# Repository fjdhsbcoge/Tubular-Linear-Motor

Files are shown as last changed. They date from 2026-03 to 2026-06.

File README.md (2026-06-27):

# Tubular Linear Motor

Open-source tubular linear motor with FOC control. **Parametric design** — scalable dimensions with invariant ratios.

## Design Overview

This project provides a **general parametric design** for tubular linear motors that can be scaled to different sizes while maintaining proper field geometry. The repository also documents a **specific test setup** being built for initial verification.

## CAD Design

Cross-sectional view showing the internal structure with stator magnets and coil arrangement:

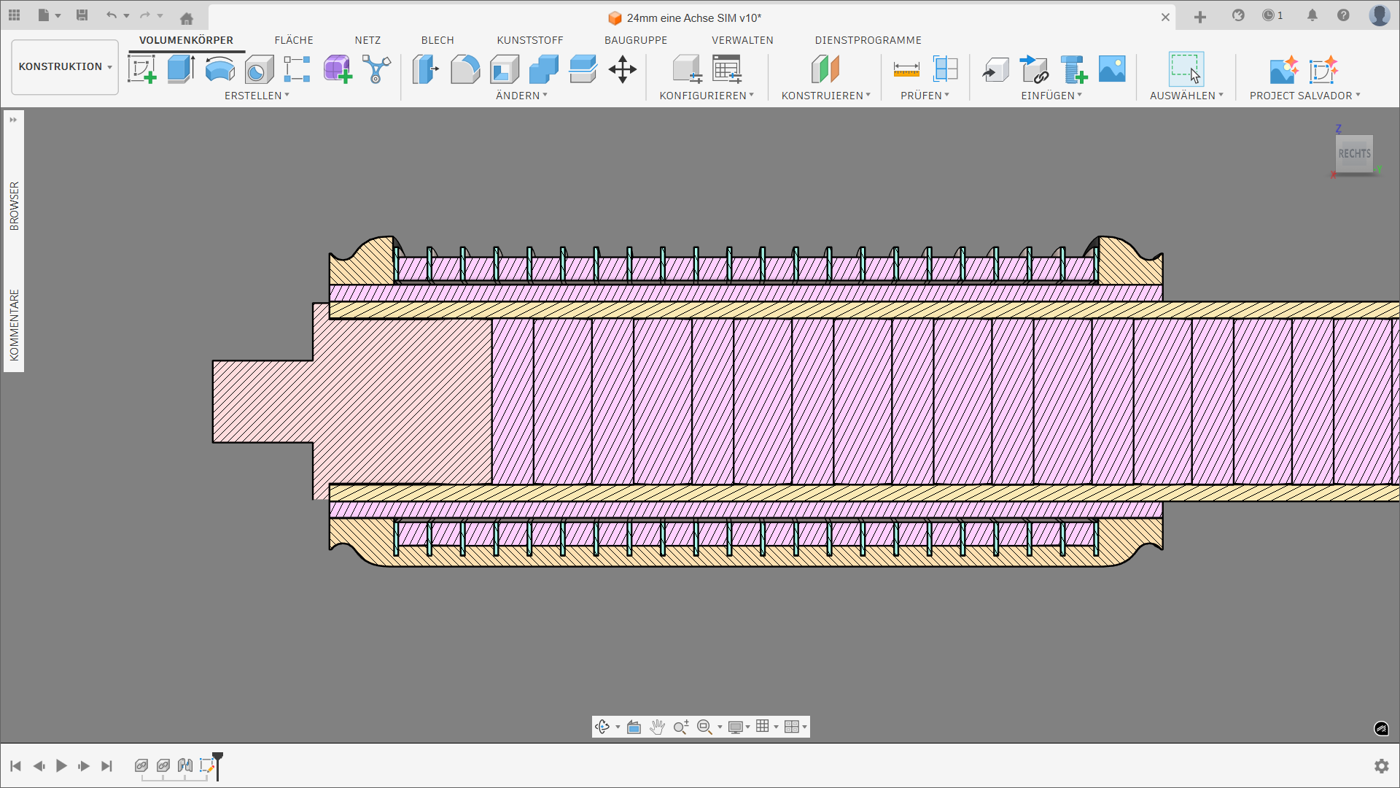
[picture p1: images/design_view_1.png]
Design View 1 - Cross Section


3D render showing the complete mover assembly with copper windings and carbon fiber housing:

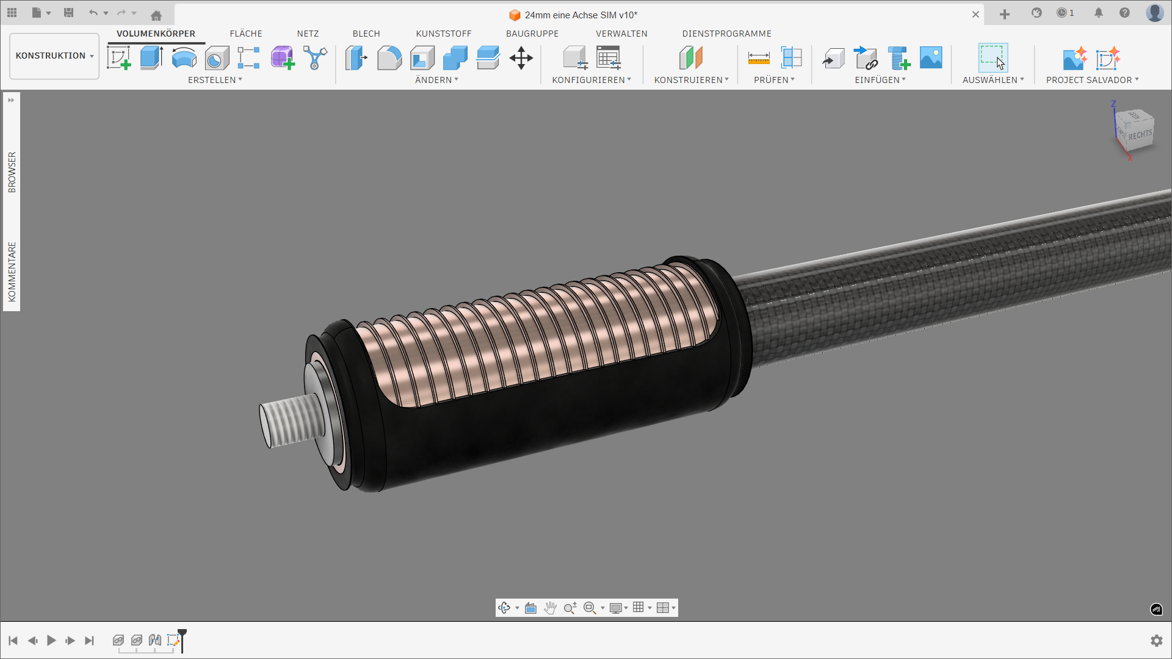
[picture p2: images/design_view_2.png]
Design View 2 - 3D Render


## Magnetic Field Simulations

The motor operates on a magnetic gearing principle where two sine-wave fields interlock like gear teeth. FEMM simulations visualize this interaction: field lines show the flux paths from the stator magnets, while the B-field plots demonstrate the sinusoidal pattern that creates the "magnetic gear rack" the mover engages with.

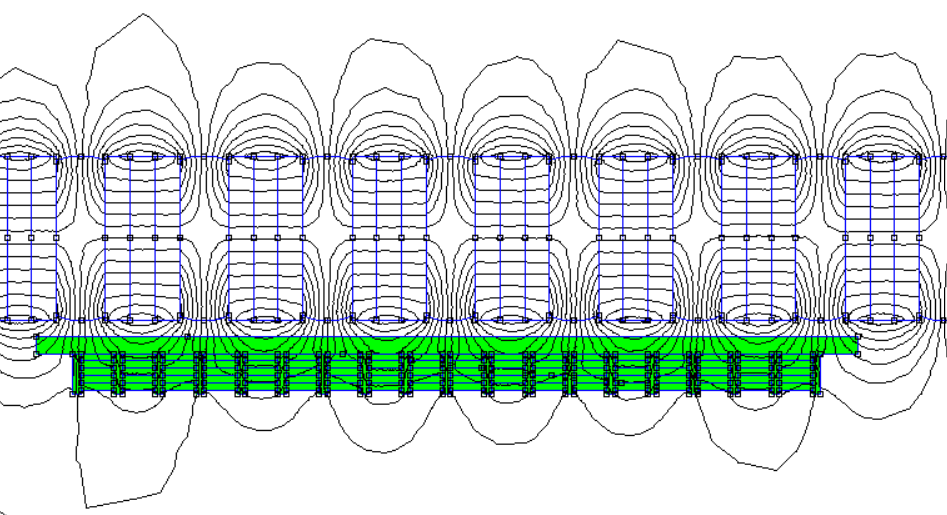
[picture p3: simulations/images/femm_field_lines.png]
Field Lines

*Magnetic field lines from the stator permanent magnets*

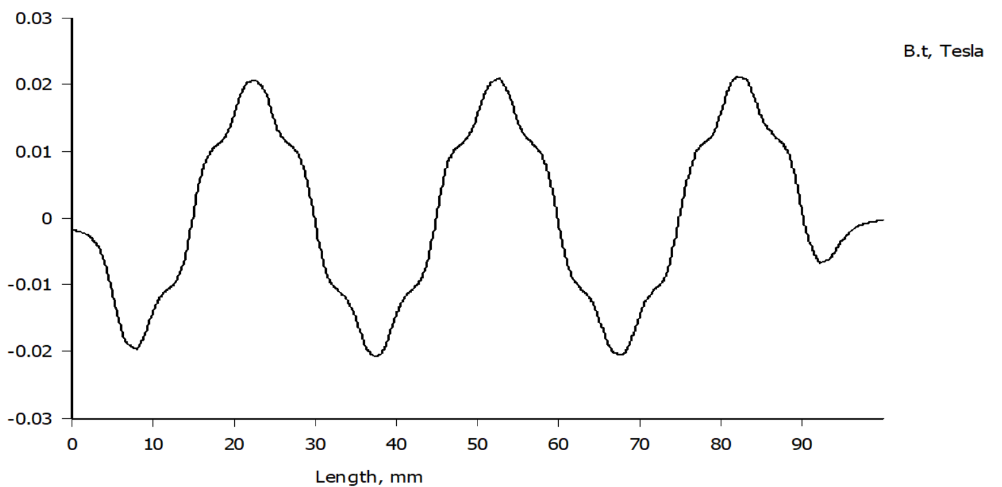
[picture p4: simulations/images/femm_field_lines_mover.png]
B-Field Plot

*Flux density along the mover length*

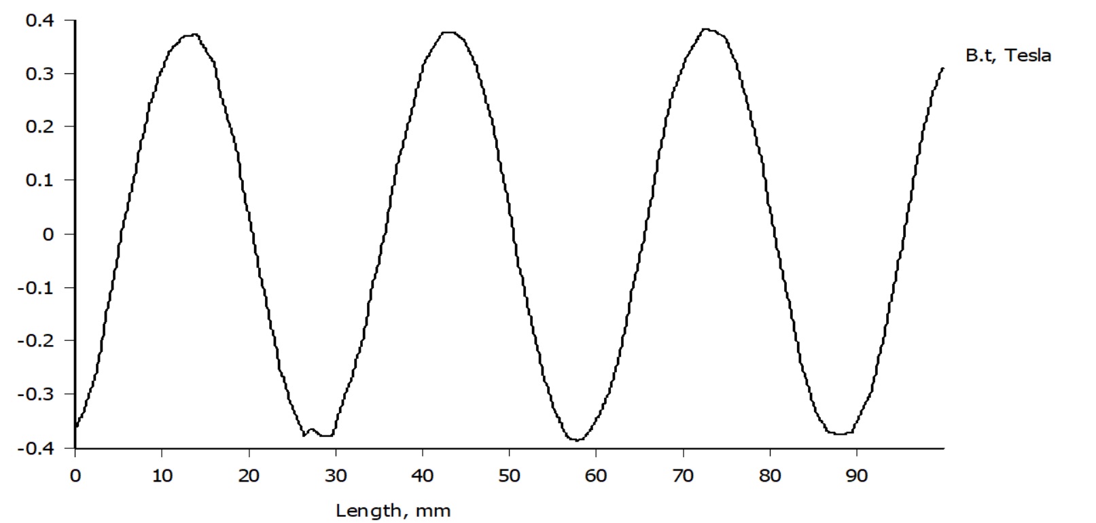
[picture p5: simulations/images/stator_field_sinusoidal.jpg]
Stator Field

*Sinusoidal B-field along the stator — each period corresponds to one pole pair (N-S), forming the "teeth" of the magnetic gear*

### Parametric Design Principles

The motor follows these invariant relationships:

| Ratio | Value | Description |
|---|---|---|
| Coil width / Pole pitch | 1/6 | 6 coils per pole pitch (AbCaBc) |
| Spacer width / Magnet width | 0.9–1.2 | Flux shaping optimization |
| Edge rounding | ~5 × disk diameter | Sinusoidal field formation |

**General Formula:**
```
Mover: AbCaBc repeated X times
Width of one AbCaBc block = Pole pitch (λ)
Total mover length = X × λ
```
### Test Setup (Being Verified)

The simulations and CAD files in this repository represent a specific test configuration:

| Parameter | Value |
|---|---|
| Outer Diameter | 20 mm |
| Pole Pitch (λ) | 30 mm |
| Coil Width | 5 mm (λ/6) |
| Mover Length | 90 mm (3× λ) |
| Simulated Force | 60 N at 2 A |

See [docs/DESIGN_PRINCIPLES.md](docs/DESIGN_PRINCIPLES.md) for complete scaling guidelines and how to choose electrical parameters (resistance, inductance) based on driver capabilities and force requirements.

## Update July 2026:

Back EMF was measured, moving the coils by hand over the stator arrangement fast gives this voltage response:

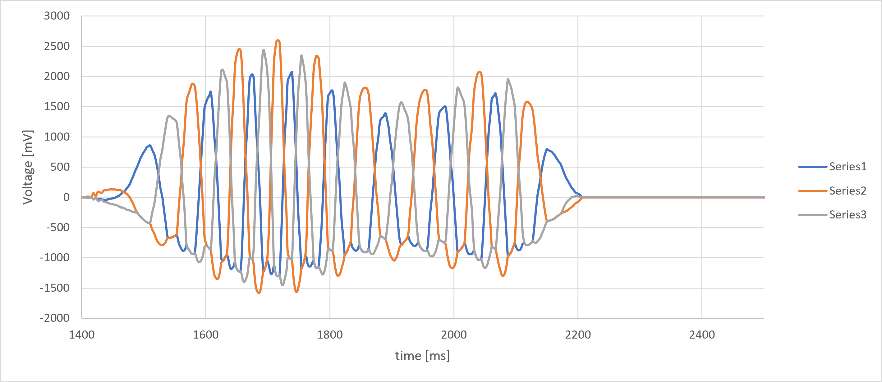
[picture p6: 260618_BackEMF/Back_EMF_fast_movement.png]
BACK EMF moving the protoype mover by hand fast


The voltage lines show a threephase response, exactly what you expect. Reversely, applying a sinusoidal three phase current on the motor will create a force and movement.

## Motor design via Excel and FEMM

The "magnetical gear" configuration was designed by using FEMM and Excel.
For a deep dive look into Simulation.

The goal was to create a motor that also uses the current flowing back from the starpoint. 
(eg. Phase A is energized with 2A, Phase B and Phase C = -1A (Kirchhoffs Law)).

## Documentation

| Document | Content |
|---|---|
| [docs/PRINCIPLE.md](docs/PRINCIPLE.md) | Physics explanation |
| [docs/WINDING_CONFIG.md](docs/WINDING_CONFIG.md) | 3-phase winding theory |
| [docs/DESIGN_PRINCIPLES.md](docs/DESIGN_PRINCIPLES.md) | **Parametric design & test setup specs** |
| [docs/BUILDING.md](docs/BUILDING.md) | Construction guide |

## Repository

```
├── docs/               # Documentation
├── cad/                # CAD files (.step, .f3z)
├── simulations/        # FEMM + Python simulations
├── data/               # Force profiles (Excel + CSV)
└── images/             # 3D renders & plots
```

## Verification Plan

| Step | Method | Status |
|---|---|---|
| 1. FEMM simulation | Static field + force | ✓ Complete |
| 2. Python dynamics | MMK traveling wave | ✓ Complete |
| 3. Static force test | Measure F vs I | Pending |
| 4. Dynamic test | FOC velocity control | Pending |
| 5. Performance | Efficiency, thermal | Pending |

## License

See [LICENSE](LICENSE).

---

*Parametric tubular linear motor. Pole pitch λ = 30mm, 24mm diameter, 3-phase FOC.*

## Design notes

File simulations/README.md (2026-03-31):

# FEMM Simulations

This directory contains FEMM simulation files.

## Files

| File | Description |
|---|---|
| `config1_20mm.FEM/.ans` | Phase A excited |
| `config1_20mm_phaseB.FEM/.ans` | Phase B excited |
| `config1_20mm_phaseC.FEM/.ans` | Phase C excited |
| `linearMotorThreephase.mo` | Modelica circuit model (R=5.6Ω, L=1.15mH) |
| `Config1_forceripple.lua` | Force ripple automation scripts |

## Method

1mm slice simulated in 2D, forces multiplied by circumference (81.68 mm).

## Results

- Peak B-field: ~0.02 T
- Field pattern: Sine wave, 30 mm period
- See `images/` for field visualizations

## Materials

- N40 magnets: Hc = 970 kA/m
- 1006 Steel: μr = 1404
- 0.4 mm Litz wire

See `FILE_GUIDE.md` for detailed file descriptions.

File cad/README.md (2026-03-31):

# CAD Files

This directory contains CAD models for manufacturing the tubular linear motor.

## Files

| File | Format | Description |
|---|---|---|
| `24mm eine Achse SIM.step` | STEP | Universal CAD format, importable in most CAD software |
| `24mm eine Achse SIM.f3z` | Fusion 360 | Native Fusion 360 archive with full history |

## Contents

The CAD model includes:

### Stator Components
- Steel tube (housing)
- Magnet disks
- Steel flux return disks
- Ferromagnetic field shapers
- Complete stack assembly

### Mover Components
- Laminated core with slots
- Coil winding regions
- Housing/mounting structure
- End caps

### Assembly
- Mover positioned over stator
- Air gap clearance visible
- Overall dimensions

## Dimensions

| Parameter | Value |
|---|---|
| Tube outer diameter | 24 mm |
| Tube inner diameter | 20 mm |
| Pole pitch | 15 mm |
| Air gap | ~0.5-1 mm |
| Mover outer diameter | ~28 mm |

## Usage

### Viewing
- **Fusion 360**: Open `.f3z` file for full parametric model
- **Any CAD**: Import `.step` file
- **Free viewers**: Use eDrawings, FreeCAD, or similar

### Manufacturing
- Export individual parts from the assembly
- Generate 2D drawings with tolerances
- Create toolpaths for CNC/lathe

### Modification
- Change pole pitch, diameter, or length
- Adjust magnet/steel thickness
- Modify slot geometry

## Exporting Parts

From Fusion 360:
1. Open `.f3z` archive
2. Navigate to component in browser
3. Right-click → "Export as STL/STEP"
4. Use for 3D printing or machining

## Notes

- Model is parametric — change dimensions in Fusion 360
- STEP file is static geometry for reference
- Some features may be simplified for manufacturing
- Verify critical dimensions before production

---

*See [docs/BUILDING.md](../docs/BUILDING.md) for assembly instructions.*

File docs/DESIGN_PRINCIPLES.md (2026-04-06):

# Tubular Linear Motor - Design Principles

This document describes the **general parametric design** that can be scaled, and the **specific test setup** used for initial verification.

---

## General Design (Parametric)

The motor design is parametric — dimensions can be changed while maintaining proportional relationships that ensure proper operation.

### Stator Design

**Magnets and Spacers (tightly stacked inside a thin tube):**

| Parameter | Guideline | Rationale |
|---|---|---|
| Magnet Pattern | NS=SN=NS=SN... | Alternating poles for sinusoidal field |
| Spacer Material | C15 or similar low-carbon steel | High permeability, easy to machine |
| Spacer Edge Rounding | ~5 × disk diameter | Shapes field into clean sine wave |
| Spacer Width | 90-120% of magnet width | Optimizes flux shaping |
| **Pole Pitch (λ)** | **NS=SN=** (one full period) | Fundamental design unit |

**Pole Pitch Definition:**
The pole pitch λ is the distance from one N pole to the next N pole (N→S→N). One pole pitch = two magnets + two spacers.

### Mover Design

**Winding Pattern:**
```
AbCaBc AbCaBc AbCaBc ... (repeated X times)
```

| Parameter | Guideline | Rationale |
|---|---|---|
| Pattern | AbCaBc | 3-phase, 6 coils per pole pitch |
| Coil Width | λ/6 (pole pitch ÷ 6) | 60° electrical spacing |
| Total Mover Length | X × λ | X = number of AbCaBc repeats |
| Phases | 3, star-connected | Standard BLDC configuration |

**Coil Layout per Pole Pitch:**
```
Position:  0      λ/6    2λ/6   3λ/6   4λ/6   5λ/6    λ
           [A]    [b]    [C]    [a]    [B]    [c]
           │      │      │      │      │      │
Phase:     U      V      W      U      V      W
Direction: +      -      +      -      +      -
```

### Electrical Parameters

Choose based on **driver capability** and **force requirements**:

| Driver Spec | Influences | Typical Range |
|---|---|---|
| Max Voltage | Max speed, back-EMF handling | 12-48V |
| Max Current | Peak force, thermal limits | 2-10A |
| PWM Resolution | Current control precision | 8-12 bit |

**Design Equations:**
```
V_back_EMF = N × B × v × l  (speed voltage)
R_phase    = V_driver / I_max (for thermal limit)
L_phase    = τ_electrical × R (for current bandwidth)
```

Where:
- N = turns per coil
- B = peak air-gap flux density
- v = max velocity
- l = active conductor length
- τ_electrical = electrical time constant (typically 1-5 ms)

---

## Test Setup (Specific Implementation)

This is the specific configuration being built and simulated for initial verification.

### Physical Dimensions

| Parameter | Value | Notes |
|---|---|---|
| Outer Diameter | 24 mm | Tube OD |
| Pole Pitch (λ) | 30 mm | N-to-N distance |
| Magnet Diameter | 18 mm | Stator magnets |
| Coil Inner Diameter | 25 mm | Mover bore |
| Coil Outer Diameter | 35 mm | Mover OD |
| Coil Width | 5 mm | λ/6 = 30/6 |
| Mover Length | 90 mm | 3 × λ (three AbCaBc repeats) |

### Materials

| Component | Material | Specification |
|---|---|---|
| Magnets | N40 | Br = 1.3 T, Hc = 970 kA/m |
| Spacers | Steel 1006 | μr = 1404, rounded edges |
| Wire | 0.4 mm Litz | σ = 58 MS/m, 18 coils total |
| Tube | Thin-wall stainless | Contains magnet stack |

### Electrical (Measured/Simulated)

| Parameter | Value | Source |
|---|---|---|
| Phase Resistance | 4.0 Ω | Design target |
| Phase Inductance | ~1.15 mH | FEMM simulation |
| Mutual Inductance | ~-0.46 mH | FEMM simulation |
| Nominal Current | 2 A | Thermal limited |
| **Simulated Force** | **60 N at 2 A** | FEMM + Excel |

### Coil Configuration Detail

**18 coils total: A-b-C-a-B-c repeated 3 times**

```
Position (mm):  0   5   10  15  20  25  30  35  40  45  50  55  60  65  70  75  80  85
Coil:           A   b   C   a   B   c   A   b   C   a   B   c   A   b   C   a   B   c
Phase:          U   V   W   U   V   W   U   V   W   U   V   W   U   V   W   U   V   W
Block:          └──────── Block 1 ────────┘   └──────── Block 2 ────────┘   └──────── Block 3 ────────┘
```

### Driver Configuration

| Parameter | Value |
|---|---|
| Driver | SimpleFOC-compatible |
| Supply Voltage | 12-24V (configurable) |
| PWM Output | 0-4V unipolar (bipolar currents via floating neutral) |
| Control | FOC (Field-Oriented Control) |
| Current Limit | 2A continuous |

---

## Scalability Notes

The design can be scaled while maintaining these **invariant ratios**:

```
Coil width / Pole pitch = 1/6
Spacer width / Magnet width = 0.9-1.2
Pole pitch / Tube diameter ≈ 1-2 (for good field geometry)
```

**Scaling effects:**
- **Larger pole pitch**: Lower electrical frequency for same velocity, higher voltage for same speed
- **More coil blocks**: Higher force density, longer mover
- **Thicker magnets**: Stronger field, higher force, more expensive

---

## Verification Plan

| Step | Method | Status |
|---|---|---|
| 1. FEMM simulation | Static field + force calculation | ✓ Complete |
| 2. Python dynamics | MMK traveling wave simulation | ✓ Complete |
| 3. Static force test | Measure force vs current | Pending |
| 4. Dynamic test | Velocity control with FOC | Pending |
| 5. Performance validation | Force, efficiency, thermal | Pending |

---

*For winding theory details, see WINDING_CONFIG.md. For build instructions, see BUILDING.md.*

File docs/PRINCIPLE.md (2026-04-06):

# Principle of Operation

## Magnetic Gearing

Two sine-wave magnetic fields interlock like gear teeth to produce linear force without contact.

**Stator (inside tube):**
- Alternating N-S magnets with steel disks
- Rounded ferromagnetic discs shape the field into a sine wave
- Creates outward sine-wave field (static)

**Mover (surrounds stator):**
- 3-phase coils in ferromagnetic slots
- Creates traveling sine-wave field (inward)

**Force:** Fields mesh like gear teeth. When mover field travels (driven by 3-phase currents), it pulls the mover along.

```
Stator:  ~~~ ~~~ ~~~ ~~~  (static outward)
             ↕ ↕ ↕ ↕
Mover:   ~~~ ~~~ ~~~ ~~~  (traveling inward)
             ↑ ↑ ↑ ↑
           Force
```

**Key:** Coil width = Pole pitch / 6 = 5 mm (for 30 mm pole pitch)

**Note:** This simplified Python simulation shows **relative force** values for visualization. The actual **60 N at 2 A** comes from detailed FEMM simulations with full 2D geometry including radial flux and ferromagnetic effects.

---

## Specifications

### General Parameters

| Parameter | Value |
|---|---|
| Diameter | 24 mm |
| Pole Pitch (N-to-N) | 30 mm |
| Pole Width (N-to-S) | 15 mm |
| Circumference | 81.68 mm (from FEMM) |
| Phases | 3, star-connected |
| Control | FOC |

### Mover (Test Setup)

| Parameter | Value |
|---|---|
| Magnet Diameter | 18 mm |
| Coil Diameter | 25 mm - 35 mm |
| Coil Configuration | 15 × 5 mm segments |
| Total Coil Length | 90 mm |
| **Simulated Force** | **60 N at 2 A** |

> **Note:** With higher financial effort (better magnetic materials, optimized coil winding, enhanced cooling), the design can be pushed to achieve significantly higher forces.

---

## Field Profile

FEMM simulations show the magnetic field distribution throughout the motor: field lines visualize the flux paths from the stator magnets, while the B-field plots demonstrate the sinusoidal pattern that creates the "magnetic gear rack" the mover engages with.

Field Lines
*Magnetic field lines from the stator permanent magnets*

B-Field Plot
*Flux density along the mover length*

Stator Field
*Sinusoidal B-field along the stator — each period corresponds to one pole pair (N-S), forming the "teeth" of the magnetic gear*

**Simulation Results:**
- Peak B-field: ~0.02 T
- Period: 30 mm (pole pitch)
- Clean sine wave confirms field shaping works

## Star-Connected BLDC Driver Simulation

The motor uses a star-connected 3-phase winding configuration (AbCaBc) with SimpleFOC control. The simulation below models the **test setup** configuration: coils distributed **along the motor length**, each interacting with the **local stator B-field** at its position.

**Note:** This simulation uses the specific test setup parameters (30mm pole pitch, 6 coils spanning one pole pitch). The general parametric design allows scaling these dimensions — see [DESIGN_PRINCIPLES.md](DESIGN_PRINCIPLES.md) for scaling guidelines.

### Test Setup Coil Layout

```
Position:   0mm    5mm    10mm   15mm   20mm   25mm   30mm (pole pitch)
            [A]    [b]    [C]    [a]    [B]    [c]
            │      │      │      │      │      │
Phase:      U      V      W      U      V      W
Direction:  +      -      +      -      +      -
```

The 6 coils are physically separated along the mover, spanning one pole pitch (30 mm). Each coil produces MMK (magnetomotive force) that interacts with the **local** sinusoidal B-field from the stator magnets.

### Simulation Results

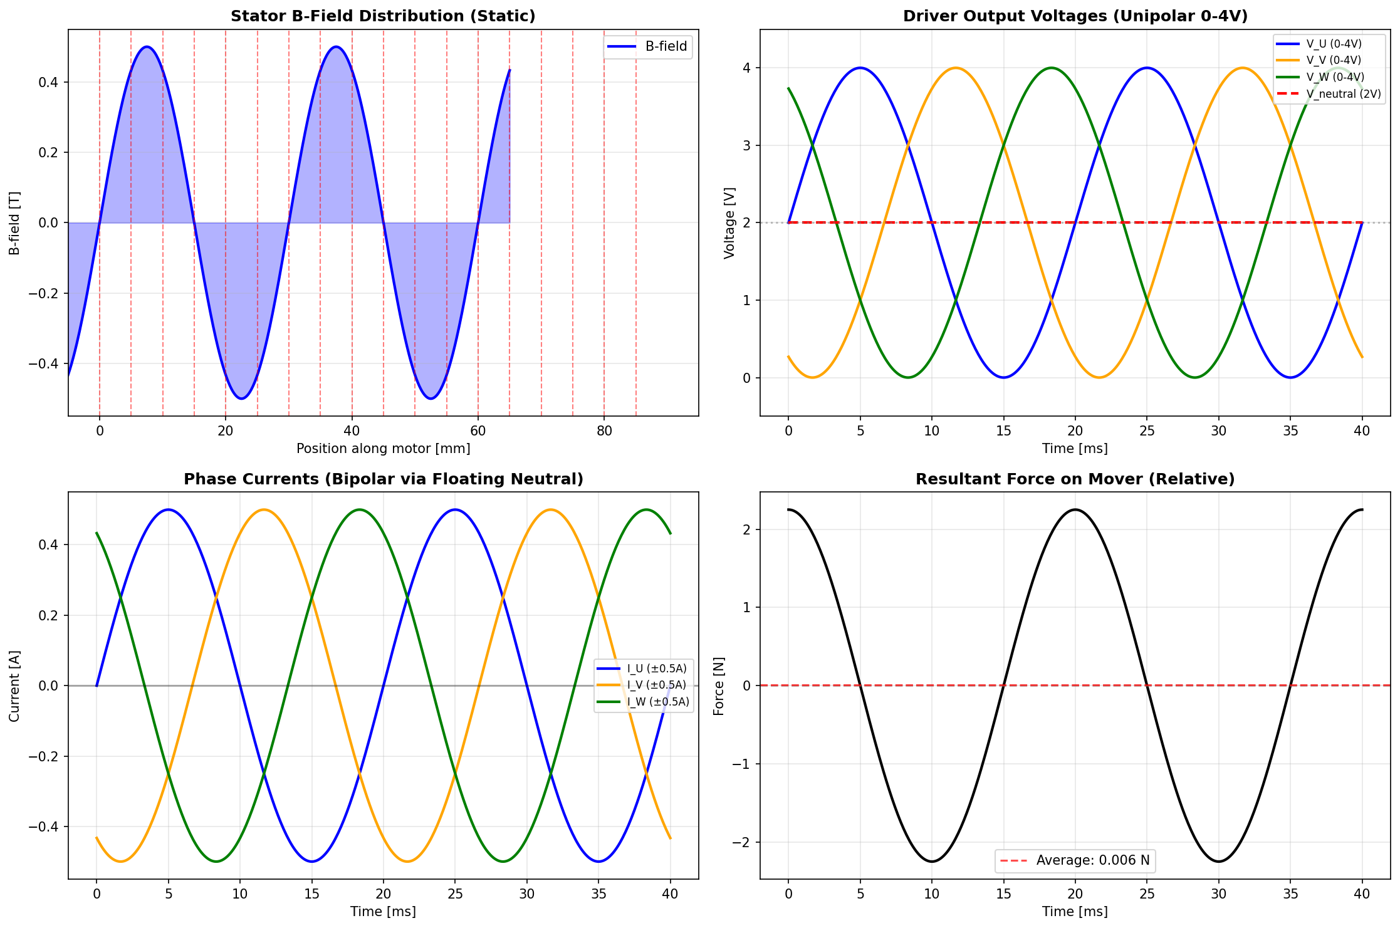
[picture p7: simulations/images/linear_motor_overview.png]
Linear Motor Overview

*Top-left: Static sinusoidal B-field from stator magnets (period = 30 mm pole pitch). Top-right: Bipolar phase currents (±0.5A). Bottom-left: Space-time diagram showing the traveling MMK wave moving along the motor length. Bottom-right: Resultant force on mover (oscillates because at standstill, the relative alignment changes with electrical angle).*

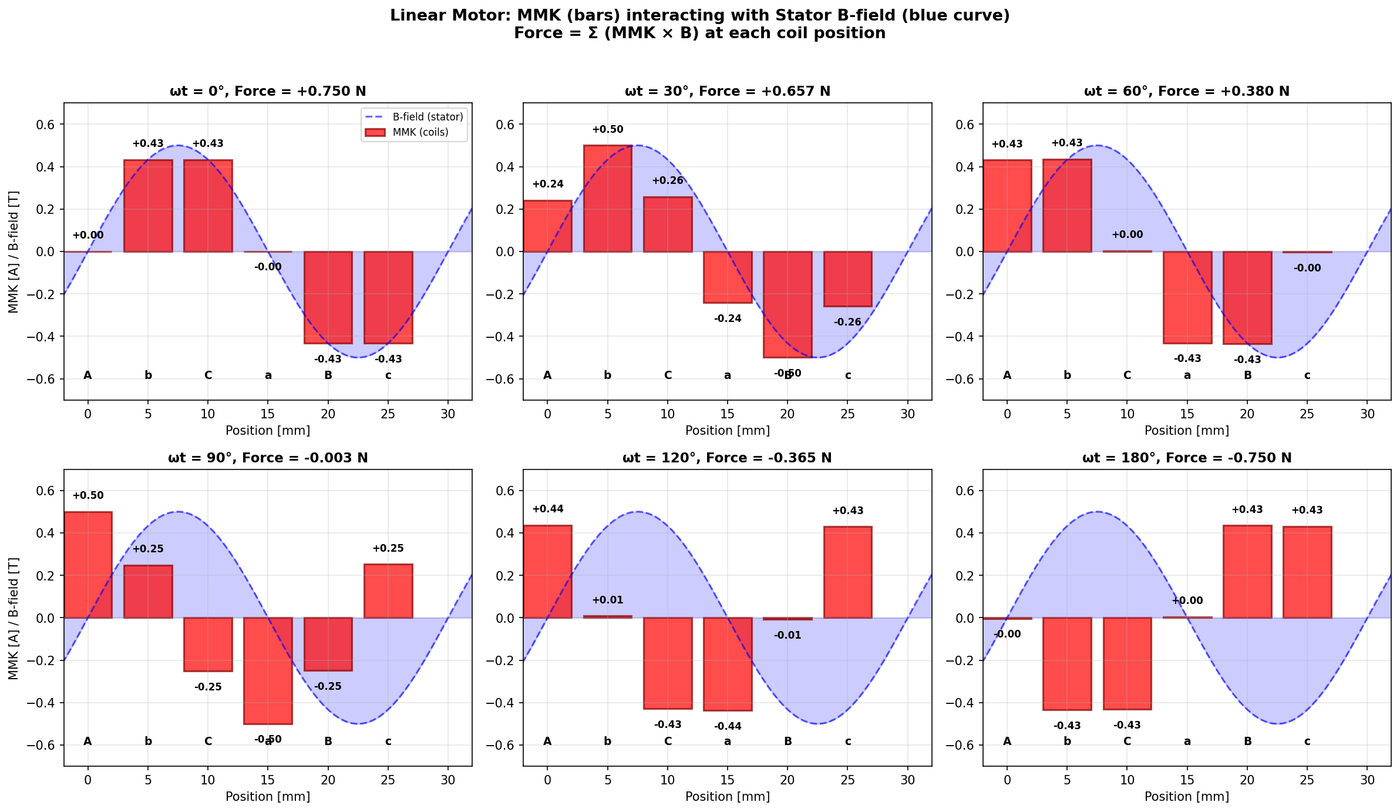
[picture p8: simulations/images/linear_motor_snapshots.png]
Linear Motor Snapshots

*MMK distribution (red bars) interacting with stator B-field (blue curve) at different electrical angles. Each coil's MMK multiplies by the local B-field to produce force. The sum across all 6 coils gives total force (shown in titles). At ωt=0°, force is maximum (+0.750 N); at ωt=90°, force crosses zero; at ωt=180°, force reverses (-0.750 N).*

### Key Physics

**Force Calculation:**
Unlike a rotating motor where all coils are at the same radius, in a linear motor:
```
F_total = Σ (MMK_coil_i × B_stator(x_coil_i)) for i = 1 to 6
```

Each coil sees a different B-field depending on its position along the stator. The traveling MMK wave (created by time-varying 3-phase currents) "locks" into the static sinusoidal B-field and pulls the mover along.

**Floating Neutral Point:**
Same as before — the star connection with isolated neutral creates bipolar currents from unipolar 0-4V PWM:
```
I_phase = (V_driver - V_neutral) / R_phase = ±0.5 A
```

**With FOC Control:**
The force oscillates in the snapshots because the mover is at a fixed position. In operation, FOC controls the phase currents to maintain the MMK wave at a constant offset (typically 90° electrical) from the stator field, producing continuous force in one direction.

### Python Simulation

See [`simulations/linear_motor_correct_physics.py`](../simulations/linear_motor_correct_physics.py) for the full simulation code.

---

*For construction details, see BUILDING.md. For winding configuration, see WINDING_CONFIG.md.*

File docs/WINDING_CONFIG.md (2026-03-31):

# Winding Configuration

From Excel: `260331 Coil Config and Force Profile.xlsx` — Sheet 1

## Coil Arrangement

18 coils in pattern: **A-b-C-a-B-c** repeating
- Uppercase (A,B,C): Clockwise winding (+)
- Lowercase (a,b,c): Counter-clockwise winding (-)
- 6 coils per phase

## Target Field Pattern (per phase)

Each phase creates this sinusoidal field across coils:
```
Coil:  1   2   3   4   5   6   7   8   9   10  11  12...
Field: -2  -1   1   2   1  -1  -2  -1   1   2   1  -1...
```

Pattern repeats every 6 coils (one pole pitch = 30 mm).

## Phase Shifts

- **Phase A**: Starts at coil 1
- **Phase B**: Shifted 2 coils (30°) — starts at -2
- **Phase C**: Shifted 4 coils (60°) — starts at -2

Electrical phase shifts: **150°** (A→B), **90°** (A→C)

These non-standard shifts optimize the traveling wave for this specific winding.

## Current Distribution

Per Kirchhoff (rows 5-7 in Excel):
- 6 coils at +2A
- 12 coils at -1A  
- Sum = 0 ✓

The -1A currents are return paths through other phases.

## 3-Phase Sum

When all phases active (row 20):
```
Result: -2, -6, -2, 2, 6, 2, -2, -6, -2...
```

Amplitude: **±6** (3× single phase)

This creates the traveling magnetic wave.

## Key Parameters

| Parameter | Value |
|---|---|
| Pole Pitch | 30 mm |
| Coils | 18 (6 per phase) |
| Coil Width | 5 mm |
| Design Current | 2A per phase |

---

*For construction, see BUILDING.md. For theory, see PRINCIPLE.md.*

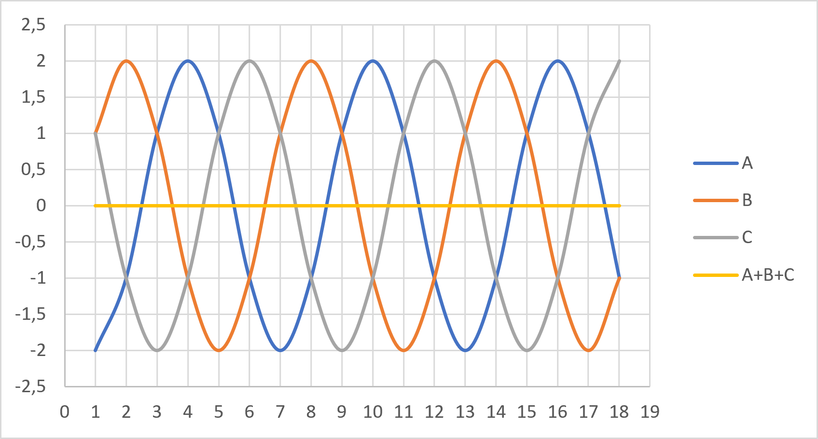
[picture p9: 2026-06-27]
simulations/images/Excel calculation.png

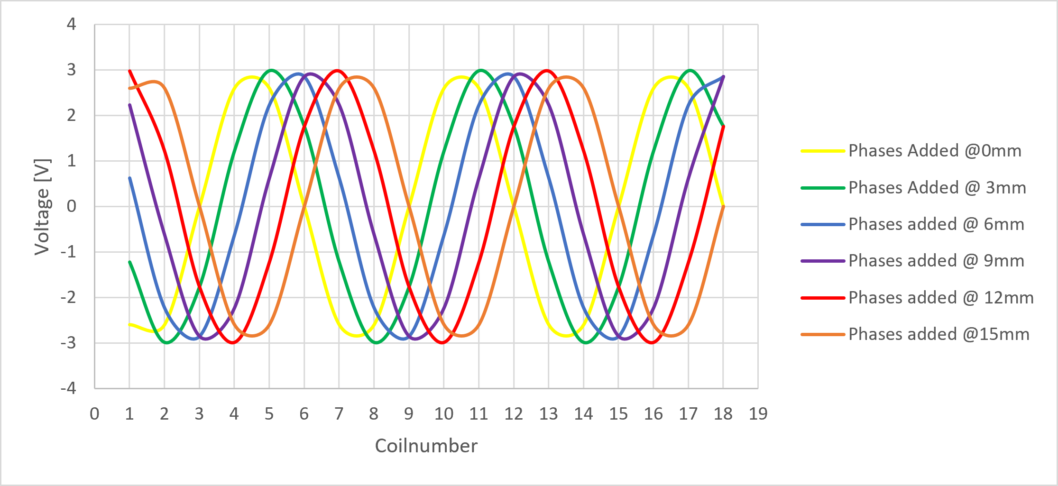
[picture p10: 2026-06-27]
simulations/images/Excel calculation2.png

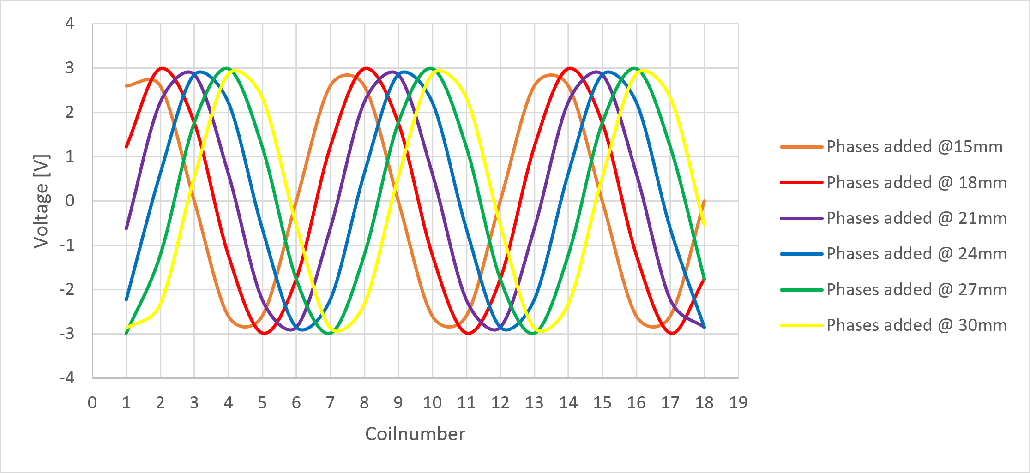
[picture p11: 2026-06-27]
simulations/images/Excel calculation3.png

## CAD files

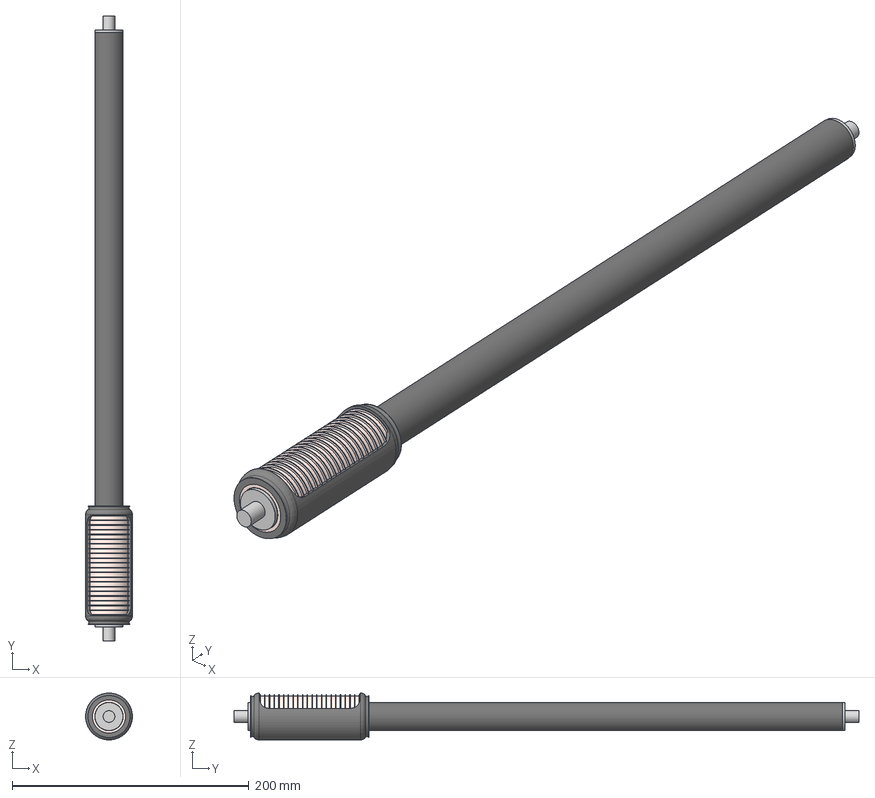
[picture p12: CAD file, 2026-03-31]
cad/24mm eine Achse SIM.step
39.6 x 528.0 x 39.6 mm
Halter
CFK Rohr
Coildholder
Graphite

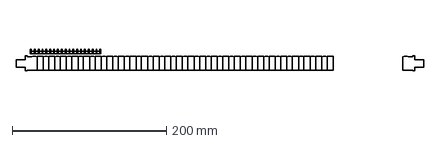
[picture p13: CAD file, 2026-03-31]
simulations/Config1_20mm.dxf
528.0 x 28.3 mm

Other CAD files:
cad/24mm eine Achse SIM.f3z

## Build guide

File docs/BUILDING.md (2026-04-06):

# Building Instructions

## BOM

### Stator
- **Carbon fiber tube**: OD 20 mm, ID 18 mm (contains magnet stack)
- N40 magnets: 20× (dia 18 mm, thickness 3-4 mm)
- 1006 steel disks: 20× (dia 18 mm, thickness 0.5-1 mm)
- Field shapers: 20× (dia 18 mm, rounded OD)

### Mover
- Core laminations: 1006 steel
- Wire: 0.4 mm Litz copper (~120 m)
- Housing: Aluminum/plastic

### Electronics
- 3-phase inverter (48V, 10A)
- FOC controller (SimpleFOC/ODrive)
- Position encoder (1000+ CPR)

---

## Assembly

### 1. Stator Stack
Order inside tube:
```
[Magnet N] - [Steel] - [Field Shaper] - [Magnet S] - [Steel] - ...
```
Bond with Loctite 638. Verify alternating polarity with compass.

### 2. Mover Winding
Pattern: **A-b-C-a-B-c** (18 coils)
- Coil width: 5 mm
- 6 coils per phase
- Alternate winding directions
- Star connection

Target resistance: 5.6 Ω per phase

### 3. Electronics
- Connect phases A, B, C to inverter
- Install encoder
- Run FOC commissioning

---

## Commissioning

1. **DC test**: Apply 12V to Phase A → mover locks
2. **Shift test**: Phase B → shifts 10 mm (1/3 pole pitch)
3. **Encoder align**: Set offset so zero electrical angle matches mechanical zero
4. **FOC tune**: Tune current PI controllers

---

## Troubleshooting

| Problem | Solution |
|---|---|
| No force | Check phase sequence |
| Weak force | Increase current limit |
| Cogging | Recalibrate encoder offset |
| Heating | Reduce current or add cooling |

---

*For winding details, see WINDING_CONFIG.md. For theory, see PRINCIPLE.md.*

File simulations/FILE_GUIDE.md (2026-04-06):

# FEMM Simulation Files

This directory contains complete FEMM simulation files for the tubular linear motor.

## File Overview

| File | Description |
|---|---|
| `config1_20mm.FEM` | Main FEMM project - Phase A excited |
| `config1_20mm.ans` | Solution file - Phase A (binary) |
| `config1_20mm_phaseB.FEM` | FEMM project - Phase B excited |
| `config1_20mm_phaseB.ans` | Solution file - Phase B (binary) |
| `config1_20mm_phaseC.FEM` | FEMM project - Phase C excited |
| `config1_20mm_phaseC.ans` | Solution file - Phase C (binary) |
| `Config1_20mm.dxf` | CAD export of geometry |
| `Config1_force_ripple_2A.txt` | Force vs. position (Phase A, 2A) |
| `Config1_force_ripple_PhaseB_2A.txt` | Force vs. position (Phase B, 2A) |
| `Config1_force_ripple_PhaseC_2A.txt` | Force vs. position (Phase C, 2A) |
| `linearMotorThreephase.mo` | Modelica 3-phase circuit simulation |
| `Config1_forceripple.lua` | FEMM automation script (Phase A) |
| `Config1_forceripple_phaseB.lua` | FEMM automation script (Phase B) |
| `Config1_forceripple_phaseC.lua` | FEMM automation script (Phase C) |

## Simulation Methodology

### Model Dimensions
- **Slice thickness**: 1 mm (2D planar simulation)
- **Model length**: 20 mm (partial stator representation)
- **Scaling**: Force results multiplied by circumference (81.68 mm)

### Materials Used

| Material | Type | Properties |
|---|---|---|
| **N40** | Permanent Magnet | Hc = 969,969 A/m, μr = 1.05, σ = 0.667 MS/m |
| **1006 Steel** | Ferromagnetic | μr = 1,404 (nonlinear), B-H curve included |
| **Air** | Non-magnetic | μr = 1 |
| **0.4mm** | Coil (Litz) | 0.4mm wire, σ = 58 MS/m, LamType = 3 (Litz wire) |
| **u1-u6** | Various | Permeability values for specific regions |

### Geometry Details

**Stator (inside tube):**
- Alternating N40 magnet disks
- 1006 Steel flux return disks
- Rounded ferromagnetic discs between magnets

**Mover (outside, green in images):**
- 3-phase winding slots
- Litz wire (0.4mm) for reduced eddy losses
- Air gap between stator and mover

**Boundary Conditions:**
- A = 0 (magnetic potential) at model edges
- Planar problem type
- Cartesian coordinates

## Force Results

### Phase A (2A current)
Peak force: **~4.8 N** (see `Config1_force_ripple_2A.txt`)

Force varies sinusoidally with position:
- Position 0 mm: Fx ≈ 0 N, Fy ≈ -3.2 N
- Position 10 mm: Fx ≈ 0.5 N, Fy ≈ -3.3 N  
- Position 20 mm: Fx ≈ 0.1 N, Fy ≈ -4.8 N
- Position 40 mm: Fx ≈ 0.4 N, Fy ≈ -3.3 N

The force ripple shows the periodic nature of the magnetic gearing.

### Phases B and C
Similar force profiles shifted by 120° and 240° electrical degrees.

**Note:** Fx is the useful force in the direction of motion. Fy is the normal force (attractive/repulsive).

## How to Use These Files

### Opening in FEMM
1. Download FEMM from https://www.femm.info/
2. Open `.FEM` file: File → Open
3. View geometry and materials
4. To see results: File → Open → select corresponding `.ans` file

### Viewing Force Data
The `.txt` files contain tab-separated data:
```
Position_mm    Fx_N        Fy_N
0              0           -3.22486...
1              -0.3588...  -3.21832...
...
```

Import into Excel, Python, MATLAB for plotting.

### Running New Simulations
1. Modify geometry in `.FEM` file (if desired)
2. Mesh: Operations → Mesh
3. Solve: Operations → Solve
4. Post-process: View → Field or use Lua scripts

## Simulation Parameters

From `config1_20mm.FEM`:
```
[Format]      = 4.0
[Frequency]   = 0 (DC/static)
[Precision]   = 1e-8
[MinAngle]    = 30°
[DoSmartMesh] = 1 (adaptive meshing)
[Depth]       = 1 mm
[LengthUnits] = millimeters
[ProblemType] = planar
```

## Key Insights

1. **N40 Magnets**: High-grade neodymium (Hc ≈ 970 kA/m)
2. **1006 Steel**: Low-carbon steel for flux paths (nonlinear B-H)
3. **Litz Wire**: 0.4mm strands reduce AC losses
4. **Force Ripple**: ~4.8N peak with sinusoidal variation
5. **Scaling**: 1mm slice × 87.976mm circumference = full 3D force

## Visualization

See `images/` folder for:
- Field line plots showing flux distribution
- B-field profiles confirming sine-wave shape

## DXF Export

`Config1_20mm.dxf` contains the 2D geometry suitable for:
- CAD import (AutoCAD, SolidWorks, etc.)
- Laser cutting patterns
- Manufacturing drawings

## Notes

- `.ans` files are binary and large (~170 MB each)
- They contain the mesh and field solution
- Open with corresponding `.FEM` file to view results
- FEMM is Windows-only but runs via Wine on Linux/Mac

---

## Modelica Circuit Simulation (`linearMotorThreephase.mo`)

This file contains a **3-phase electrical circuit model** of the linear motor for system-level simulation.

### Model Components

| Component | Value | Description |
|---|---|---|
| **Resistance (R)** | 4.0 Ω | Phase resistance (measured from test setup) |
| **Self Inductance (L)** | 1.15 mH | Phase self-inductance (FEMM) |
| **Mutual Inductance (M)** | -0.46 mH | Coupling between phases |
| **Voltage (V_peak)** | 8 V | Peak drive voltage |
| **Frequency (f)** | 50 Hz | Drive frequency |

### Circuit Topology

The model implements a **star-connected 3-phase RL circuit**:

```
Phase A: SineVoltage → Resistor (5.6Ω) → Inductor (1.15mH) → CurrentSensor
Phase B: SineVoltage → Resistor (5.6Ω) → Inductor (1.15mH) → CurrentSensor  
Phase C: SineVoltage → Resistor (5.6Ω) → Inductor (1.15mH) → CurrentSensor

All phases connected to common floating neutral point
```

### Phase Voltages

3-phase sine waves with 120° (2π/3) displacement:
- **Phase A**: sin(2πft - 2.618) 
- **Phase B**: -sin(2πft + 2.618)  
- **Phase C**: sin(2πft + 1.571)

### Mathematical Sub-Model

The file includes `LinearMotor_MathOnly` — a pure equation-based model:

```modelica
// 7 variables, 7 equations (determined system)
Variables: i_a, i_b, i_c, v_La, v_Lb, v_Lc, v_n

// KVL for each phase
V_peak * sin(2πft - 2.618) - v_n = R*i_a + v_La;
-V_peak * sin(2πft + 2.618) - v_n = R*i_b + v_Lb;
V_peak * sin(2πft + 1.571) - v_n = R*i_c + v_Lc;

// Mutual inductance coupling
v_La = L*der(i_a) + M*der(i_b) + M*der(i_c);
v_Lb = M*der(i_a) + L*der(i_b) + M*der(i_c);
v_Lc = M*der(i_a) + M*der(i_b) + L*der(i_c);

// KCL (floating neutral)
i_a + i_b + i_c = 0;
```

### Running the Simulation

1. Install **OpenModelica** (https://openmodelica.org/)
2. Open `linearMotorThreephase.mo`
3. Simulate with appropriate time step
4. Plot phase currents vs. time

### Applications

- Verify current ripple under load
- Analyze transient response
- Design current controllers
- Validate FOC algorithms

### Key Parameters from FEMM + Measurements

The electrical parameters were derived from:
- FEMM simulations (inductance)
- Coil resistance measurements
- Mutual inductance from coupled FEMM runs

These values enable accurate electrical-thermal co-simulation.

---

## FEMM Automation Scripts (Lua)

The `.lua` files automate force ripple analysis in FEMM.

### How the Scripts Work

Each script (`Config1_forceripple.lua`, `Config1_forceripple_phaseB.lua`, `Config1_forceripple_phaseC.lua`) performs:

1. **Initialize** output file for force data
2. **Loop** through mover positions (0 to 60 mm in 60 steps)
3. **At each position:**
   - Solve the magnetic field (`mi_analyze()`)
   - Load solution (`mi_loadsolution()`)
   - Select mover group (`mo_groupselectblock(1)`)
   - Calculate forces (`mo_blockintegral(18/19)`)
   - Write position, Fx, Fy to file
4. **Move** the mover to next position (`mi_movetranslate`)
5. **Repeat** until complete

### Script Parameters

```lua
local pole_pitch = 15.0     -- 15 mm pole pitch
local steps = 60            -- 60 position steps
local total_travel = 60     -- 60 mm total travel
local move_group = 1        -- FEMM group ID for mover
```

### Force Calculation

FEMM block integrals used:
- **Integral 18**: x-component of force (Fx)
- **Integral 19**: y-component of force (Fy)

These use the **Maxwell stress tensor** method for force calculation.

### Running the Scripts

1. Open FEMM and load the corresponding `.FEM` file
2. Open Lua console: View → Lua Console
3. Run script: `dofile("Config1_forceripple.lua")`
4. Results saved to `.txt` file automatically

### Output Format

```
Position_mm    Fx_N        Fy_N
0              0           -3.224...
1              -0.358...   -3.218...
...
```

### Why 3 Separate Scripts?

Each phase requires a different `.FEM` file because:
- Phase A excited → Phase B and C at 0 A
- Phase B excited → Phase A and C at 0 A
- Phase C excited → Phase A and B at 0 A

The superposition principle allows combining these for any 3-phase current combination.

---

*End of File Guide*

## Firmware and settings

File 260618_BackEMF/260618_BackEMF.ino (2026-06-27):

#include <SimpleFOC.h>

// DRV8313 pins (from your Arduino sketch)
#define INA  9   // PWM pins!
#define INB  10
#define INC  11
#define ENA  7   // Enable pins
#define ENB  6
#define ENC  5

// 1 pole-pair = 1 pole-pitch = 30 mm
BLDCMotor motor = BLDCMotor(1);
BLDCDriver3PWM driver = BLDCDriver3PWM(INA, INB, INC, ENA, ENB, ENC);

// Conversion: 30 mm pole-pitch = 2π electrical radians
const float POLE_PITCH_MM = 30.0;
const float MM_TO_RAD = 2.0 * PI / POLE_PITCH_MM;  // 0.2094 rad/mm
const float R_PHASE = 4.8;   // Ohm
const float KT = 6.29;       // N/A (from your back-EMF)

void setup() {
  Serial.begin(115200);
  delay(1000);

  driver.voltage_power_supply = 12;  // Your supply voltage
  driver.voltage_limit = 3.0;        // START LOW! ~0.6A at stall
  driver.init();

  motor.linkDriver(&driver);
  motor.controller = MotionControlType::velocity_openloop;
  motor.voltage_limit = 3.0;         // Same as driver limit
  motor.init();

  Serial.println("Motor ready");
}

void loop() {
  // --- Test 1: Move at 50 mm/s for 2 seconds ---
  float target_mm_s = 50.0;
  float target_rad_s = target_mm_s * MM_TO_RAD;
  
  motor.move(target_rad_s);
  delay(2000);

  // --- Stop (velocity = 0) ---
  motor.move(0);
  delay(1000);
}

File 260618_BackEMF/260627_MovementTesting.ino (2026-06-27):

#include <SimpleFOC.h>

// User's soldered pin configuration
#define PWM_A  6
#define PWM_B  10
#define PWM_C  5
#define EN     8

// DRV8313 fault/reset on Shield V3.2
#define DRV_RESET  A1
#define DRV_FAULT  A3

BLDCDriver3PWM driver = BLDCDriver3PWM(PWM_A, PWM_B, PWM_C, EN);
BLDCMotor motor = BLDCMotor(1);

const float POLE_PITCH_MM = 30.0;
const float MM_TO_RAD = 2.0f * PI / POLE_PITCH_MM;

float voltage_limit = 3.0;
float max_speed = 50.0;

enum MotorMode { MODE_STOP, MODE_VELOCITY, MODE_DISTANCE };
MotorMode currentMode = MODE_STOP;

float distance_velocity = 0;
unsigned long distance_start_ms = 0;
unsigned long distance_duration_ms = 0;

String inputBuffer = "";
unsigned long lastCharTime = 0;

void setup() {
  Serial.begin(115200);
  while (!Serial);
  delay(100);

  Serial.println("\n=== SimpleFOC Shield V3.2 ===");
  Serial.println("Pins: A=6, B=10, C=5, EN=8");
  Serial.println("Timer note: pins 6 and 5 share Timer0 on Arduino Uno.");
  Serial.println("This is normal but may cause slight timing jitter.\n");

  // --- DRV8313 Reset sequence (CRITICAL) ---
  // The DRV8313 can latch into a fault state and needs a reset pulse
  pinMode(DRV_RESET, OUTPUT);
  digitalWrite(DRV_RESET, HIGH);
  delay(1);
  digitalWrite(DRV_RESET, LOW);
  delay(10);
  digitalWrite(DRV_RESET, HIGH);
  Serial.println("DRV8313 reset done");

  // Check fault status
  pinMode(DRV_FAULT, INPUT);
  delay(1);
  int fault = digitalRead(DRV_FAULT);
  Serial.print("DRV_FAULT (A3) = ");
  Serial.print(fault);
  Serial.println(fault == HIGH ? " (OK)" : " (FAULT!)");

  // --- 3PWM driver init ---
  driver.voltage_power_supply = 12;
  driver.voltage_limit = voltage_limit;
  driver.init();

  motor.linkDriver(&driver);
  motor.controller = MotionControlType::velocity_openloop;
  motor.voltage_limit = voltage_limit;
  motor.init();

  Serial.println("Driver init done");
  Serial.println("Commands: H, M50, D100, S, V50, L3.0, F, R");
  Serial.print(">>> ");
}

void loop() {
  // Serial reading with timeout flush
  while (Serial.available()) {
    char c = Serial.read();
    lastCharTime = millis();
    if (c == '\n' || c == '\r') {
      if (inputBuffer.length() > 0) { processCommand(inputBuffer); inputBuffer = ""; }
    } else {
      inputBuffer += c;
    }
  }
  if (inputBuffer.length() > 0 && (millis() - lastCharTime > 50)) {
    processCommand(inputBuffer); inputBuffer = "";
  }

  // Motor control
  switch (currentMode) {
    case MODE_VELOCITY:
      motor.move(distance_velocity * MM_TO_RAD);
      break;
    case MODE_DISTANCE:
      if (millis() - distance_start_ms < distance_duration_ms) {
        motor.move(distance_velocity * MM_TO_RAD);
      } else {
        motor.move(0);
        currentMode = MODE_STOP;
        Serial.println("OK: done");
        Serial.print(">>> ");
      }
      break;
    case MODE_STOP:
    default:
      motor.move(0);
      break;
  }
}

void processCommand(String cmd) {
  cmd.trim();
  if (cmd.length() == 0) return;

  Serial.print("Received: '");
  Serial.print(cmd);
  Serial.println("'");

  char c = cmd.charAt(0);
  String rest = cmd.substring(1);
  rest.trim();
  float value = rest.toFloat();

  switch (c) {
    case 'M': case 'm':
      if (abs(value) < 0.1) { stopMotor(); }
      else {
        currentMode = MODE_VELOCITY;
        distance_velocity = value;
        Serial.print("Velocity: ");
        Serial.print(value);
        Serial.println(" mm/s");
      }
      break;

    case 'D': case 'd':
      if (abs(value) < 0.1) { stopMotor(); }
      else if (max_speed < 0.1) { Serial.println("ERR: set V first"); }
      else {
        currentMode = MODE_DISTANCE;
        distance_velocity = (value > 0) ? max_speed : -max_speed;
        distance_duration_ms = (unsigned long)(abs(value) / max_speed * 1000.0);
        distance_start_ms = millis();
        Serial.print("Distance: ");
        Serial.print(value);
        Serial.print(" mm at ");
        Serial.print(max_speed);
        Serial.print(" mm/s for ");
        Serial.print(distance_duration_ms);
        Serial.println(" ms");
      }
      break;

    case 'S': case 's':
      stopMotor();
      break;

    case 'V': case 'v':
      max_speed = abs(value);
      Serial.print("Max speed: ");
      Serial.print(max_speed);
      Serial.println(" mm/s");
      break;

    case 'L': case 'l':
      voltage_limit = abs(value);
      driver.voltage_limit = voltage_limit;
      motor.voltage_limit = voltage_limit;
      Serial.print("Voltage limit: ");
      Serial.print(voltage_limit);
      Serial.println(" V");
      break;

    case 'F': case 'f':
      {
        int f = digitalRead(DRV_FAULT);
        Serial.print("Fault status: ");
        Serial.println(f == HIGH ? "OK" : "FAULT ACTIVE");
      }
      break;

    case 'R': case 'r':
      digitalWrite(DRV_RESET, LOW);
      delay(5);
      digitalWrite(DRV_RESET, HIGH);
      Serial.println("DRV8313 reset done");
      break;

    case 'H': case 'h': case '?':
      printHelp();
      break;

    default:
      Serial.println("ERR: unknown command. Type H for help.");
      break;
  }
  Serial.print(">>> ");
}

void stopMotor() {
  currentMode = MODE_STOP;
  motor.move(0);
  Serial.println("STOP");
}

void printHelp() {
  Serial.println("--- Commands ---");
  Serial.println("M50   Move at 50 mm/s");
  Serial.println("D100  Move 100 mm");
  Serial.println("S     Stop");
  Serial.println("V50   Set max speed");
  Serial.println("L3.0  Set voltage limit");
  Serial.println("F     Check DRV8313 fault status");
  Serial.println("R     Reset DRV8313");
  Serial.println("H     Help");
  Serial.println("--- Shield info ---");
  Serial.println("DRV8313 uses 3PWM + single enable");
  Serial.println("Your pins: A=6, B=10, C=5, EN=8");
  Serial.println("Reset (A1) and Fault (A3) are auto-checked at startup");
}

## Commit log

2026-03-31 Add comprehensive documentation and FEMM simulation data
    - Complete English documentation translated from German
    - DESIGN.md: Technical explanation of magnetic gearing concept
    - BUILD_GUIDE.md: Step-by-step construction instructions
    - Force profile data from FEMM simulations (1, 4, 6 layer configs)
    - Updated README with design overview and how it works
    - Data README explaining CSV format and usage
    [force_profile_1_layer.csv, force_profile_4_layer.csv, force_profile_6_layer.csv]
2026-03-31 Add FEMM simulation visualizations and methodology
    - Field line plots showing magnetic flux distribution
    - B-field profile confirming sine-wave field concept
    - Simulation README explaining 1mm-slice methodology
    - Updated DESIGN.md with field visualization section
    - Updated main README with simulation images
2026-03-31 Add FEMM file documentation
    - FILE_GUIDE.md: Complete documentation of all simulation files
    - Material properties extracted from .FEM files (N40, 1006 Steel)
    - Force results documented (~4.8N peak at 2A)
    - Geometry and methodology explained
    - Updated simulations/README.md with file references
2026-03-31 Document Modelica circuit simulation file
    - Add linearMotorThreephase.mo to file listing
    - Document electrical parameters (R=5.6Ω, L=1.15mH, M=-0.46mH)
    - Explain 3-phase star-connected circuit topology
    - Document mathematical sub-model with 7 equations
    - Usage instructions for OpenModelica
2026-03-31 Add files via upload
    CAD files
    [24mm eine Achse SIM.f3z, 24mm eine Achse SIM.step]
2026-03-31 Restructure documentation into three main documents
    NEW DOCUMENTATION STRUCTURE:
    1. PRINCIPLE.md - Physics-based explanation of magnetic gearing
    - How sine-wave fields interlock
    - Force production mechanism
    - Synchronous operation
    - Field visualizations
    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
    [24mm eine Achse SIM.f3z, 24mm eine Achse SIM.step]
2026-03-31 Organize Excel source data in data/ folder
    - Move 260331 Coil Config and Force Profile.xlsx to data/
    - Update data/README.md with Excel file description
    - Document all 3 sheets (1-layer, 4-layer, 6-layer configs)
    [260331 Coil Config and Force Profile.xlsx]
2026-03-31 Add comprehensive winding configuration documentation
    NEW DOCUMENT: docs/WINDING_CONFIG.md
    - Complete explanation of 18-coil, 3-phase distributed winding
    - Coil arrangement: A-b-C-a-B-c pattern with alternating directions
    - Magnetic field synthesis (rows 2-4 of Excel)
    - Kirchhoff's law application (rows 5-7)
    - Simulation currents (rows 9-11)
    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
2026-03-31 Correct pole pitch from 15mm to 30mm (N-to-N distance)
    Important terminology clarification:
    - Pole Pitch = N-to-N distance = 30mm (full electrical cycle)
    - Pole Width = N-to-S distance = 15mm (one physical magnet)
    Updated calculations:
    - Coil width = 30mm/6 = 5mm (was 2.5mm)
    - Speed at 50Hz = 0.75 m/s (was 0.375 m/s)
    - Force ripple period = 7.5mm (was 3.75mm)
    - Commissioning step sizes = 10mm and 20mm (were 5mm and 10mm)
    Files updated:
    - README.md: Quick specs and closing note
    - PRINCIPLE.md: Speed calculation, field period
    - DESIGN_PRINCIPLES.md: System specs, coil geometry, trade-offs
    - BUILDING.md: Tube length formula, commissioning steps
    - WINDING_CONFIG.md: Pole pitch parameter
2026-03-31 Simplify and condense all documentation
    Reduced documentation to essential information from user's files:
    - README.md: Concise overview with key specs and file references
    - PRINCIPLE.md: Brief magnetic gearing explanation
    - DESIGN_PRINCIPLES.md: System specs, materials, electrical params
    - BUILDING.md: Condensed BOM and assembly steps
    - WINDING_CONFIG.md: Focused on Excel sheet 1 data
    - simulations/README.md: Short file listing
    Key data preserved:
    - Pole pitch: 30mm (from Excel)
    - Circumference: 81.68mm (from FEMM/Excel)
    - Coil width: 5mm (30/6)
    - Force: ~0.6 N per phase (from Excel Config1)
    - 18-coil winding pattern A-b-C-a-B-c
    - Phase shifts: 150°, 90°
    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
2026-04-01 Update README with CAD images, magnetic field simulations, and test setup specs
2026-04-01 Add stator field sinusoidal plot to visualize magnetic gear concept
2026-04-06 Add BLDC star-connected motor simulation
    - Add Python simulation demonstrating floating neutral point physics
    - Shows how unipolar 0-4V PWM creates bipolar currents
    - Visualizes MMK traveling wave in AbCaBc winding configuration
    - Add generated plots to README and PRINCIPLE documentation
2026-04-06 Fix MMK visualization - verify sum calculation
    Add verification markers showing that individual coil contributions
    correctly sum to the resultant MMK at sampled points.
    Red stars at θ=0° confirm the mathematical correctness.
2026-04-06 Replace incorrect angular simulation with correct linear motor physics
    The previous simulation treated coils as angular positions around a
    rotation, which is wrong for a tubular linear motor.
    New simulation (linear_motor_correct_physics.py) models:
    - 6 coils distributed ALONG motor length (0, 5, 10, 15, 20, 25 mm)
    - Each coil interacts with LOCAL B-field at its position
    - Force = sum of MMK × B at each coil location
    - Traveling MMK wave shown in space-time diagram
    Updated documentation in README.md and PRINCIPLE.md to explain
    the correct physics for a linear motor with distributed coils.
2026-04-06 Restructure documentation: General Design vs Test Setup
    Major documentation reorganization:
    1. DESIGN_PRINCIPLES.md - Complete rewrite:
    - Separates General (parametric) design from Test Setup
    - Documents stator design: magnets, spacers, edge rounding ratios
    - Documents mover design: AbCaBc pattern, coil width = pole_pitch/6
    - Explains how to choose R and L based on driver specs
    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
2026-04-06 Fix inconsistencies across repository
    Corrections based on test setup measurements:
    1. Resistance: Changed all 5.6Ω to 4.0Ω (latest measured value)
    - BUILDING.md, FILE_GUIDE.md, linearMotorThreephase.mo
    2. Circumference: Fixed to 81.68 mm (test setup at magnetic gap)
    - FILE_GUIDE.md (was 87.976 mm)
    3. Tube dimensions: Corrected to carbon fiber OD 20mm, ID 18mm
    - BUILDING.md (was steel 24/20mm)
    - Coil inner diameter 25mm gives 2.5mm radial gap
    4. Magnet diameter: Confirmed 18mm in test setup
    5. Force values: Clarified 60N at 2A is from FEMM
    - Python simulation now labeled "relative force"
    - README.md and PRINCIPLE.md updated with notes
    - Simplified 1D model vs full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
2026-04-06 Fix Python simulation to match test setup: 18 coils (3 blocks)
    Previous simulation only modeled 6 coils (1 block). Updated to match
    the actual test setup configuration:
    - Default n_blocks=3 (18 coils total, 90mm mover length)
    - Coil positions: [0, 5, 10, ..., 85] mm (3× AbCaBc pattern)
    - Updated plots to show all 18 coils with proper x-limits
    - Added n_blocks parameter for flexibility
    - Updated labels to show repeating A-b-C-a-B-c pattern
    Simulation now correctly represents the test setup being built.
    Force values remain relative (simplified 1D model); 60N at 2A
    is from FEMM with full 2D geometry.
2026-04-06 Add unipolar voltage plot to simulation — clarify floating neutral mechanism
    Updated linear_motor_correct_physics.py to show the complete
    signal chain:
    1. B-field distribution (spatial) with 18 coil positions
    2. Driver Output Voltages (Unipolar 0-4V) — raw PWM from SimpleFOC
    Shows floating neutral at constant 2V (red dashed line)
    3. Phase Currents (Bipolar ±0.5A) — created by (V_driver - V_neutral)/R
    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
2026-06-27 Add files via upload
    Main design document together with the FEMM simulations.
    [260627 Force Profile.xlsb.xlsx]
2026-06-27 Add files via upload
    Back EMF testing to verify motor produces and can make use of sinusoidal current
2026-06-27 Revise README with updated design principles and tests
    Updated the README to include new parametric design principles and voltage response details.
2026-06-27 Revise README to remove outdated July 2026 updates
    Moved information regarding Back EMF measurements and motor simulation details from July 2026.
